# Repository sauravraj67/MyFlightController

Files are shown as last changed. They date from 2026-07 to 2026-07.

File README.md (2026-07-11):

# MyFlightController

Screenshot 2026-07-05 180633 (1)

So I made a custom flight controller which can be used for an RC Plane . it is based on STM32 and The Flight Controller  has 2 IMU's and a barometer for precise data collection. It has connectors for 2 Servos to control the wind / 2 ESCs and a reciever . It will work on a 12V battery. 

## Features
- Base on  STM32F401CBUx 
- Has dual IMU (MPU_6050)(ICM-20948)
- Has a Barometer (BMP280)
- Works on 12 V battery
- Has multiple voltage regulators for  (5v , 3.3v , 1.8v )

- ## 📦 Bill of Materials

| Item | Quantity | Unit Price (USD) | Total Price (USD) | Source |
|---|:---:|---:|---:|---|
| PCB + PCBA | 1 | $154.46 | $154.46 | https://jlcpcb.com |
| PCB Shipping | 1 | $17.32 | $17.32 | https://jlcpcb.com |

## 💰 Cost Summary

| Category | Amount (USD) |
|---|---:|
| Total Component Cost | **$171.78** |

### Schematic
Screenshot 2026-07-05 180633 (1)

 ### PCB Design 
 
 
  ### 3D View 

  Screenshot 2026-07-05 180633 (1)

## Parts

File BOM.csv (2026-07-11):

Item | Price | Source
PCB + PCBA | 154.46 | jlcpcb.com
PCB shipping | 17.32 | jlcpcb.com
Total | 171.78 | jlcpcb.com

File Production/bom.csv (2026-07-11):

Designator | Footprint | Quantity | Value | LCSC Part #
C1, C2, C3 | 0201 | 3 | 2u2
C10, C9 | 0201 | 2 | 0.1uf
C11, C18, C19 | 0201 | 3 | 10 uf
C12 | 0201 | 1 | 0.1 uf
C13, C14 | 0201 | 2 | 100 nf
C15, C16, C17 | 0201 | 3 | 100 n
C20, C21 | 0201 | 2 | 12pf
C22, C23, C24, C25, C26, C27 | 0201 | 6 | 100 pf
C4, C6 | 0201 | 2 | 100n
C5 | 0201 | 1 | 22u
C7, C8 | 0201 | 2 | 10uf
D1, D3 | 0201 | 2 | LED
D2 | 0201 | 1 | D
F1 | 0201 | 1 | Polyfuse
J1 | USB_C_Receptacle_G-Switch_GT-USB-7010ASV | 1 | USB_C_Receptacle_USB2.0_16P
J11, J12, J3, J5 | JST_EH_B3B-EH-A_1x03_P2.50mm_Vertical | 4 | Conn_01x03_Pin
J13 | JST_EH_B4B-EH-A_1x04_P2.50mm_Vertical | 1 | Conn_01x04_Pin
J2 | AMASS_XT60-M_1x02_P7.20mm_Vertical | 1 | Conn_01x02_Pin
J4, J6 | AMASS_XT60-F_1x02_P7.20mm_Vertical | 2 | Conn_01x02_Pin
Q1 | SOT-23 | 1 | AO3401A
R1, R2 | 0201 | 2 | 33 R
R3, R4 | 0201 | 2 | 50K
R5 | 0603 | 1 | 100R
R6, R7 | 0201 | 2 | 1K
SW1 | SW_PUSH_E-Switch_FS5700DP_DPDT | 1 | SW_DPDT_x2
SW2 | SW_Tactile_Straight_KSA0Axx1LFTR | 1 | SW_Push
U1 | TSOT-23-6 | 1 | AP63203WU
U2 | TO-252-2 | 1 | L7805
U3 | InvenSense_QFN-24_4x4mm_P0.5mm | 1 | MPU-6050
U4 | Bosch_LGA-8_2x2.5mm_P0.65mm_ClockwisePinNumbering | 1 | BMP280
U5 | InvenSense_QFN-24_3x3mm_P0.4mm | 1 | ICM-20948
U6 | SOT-23-5 | 1 | LD39015M18R
U7 | QFN-48-1EP_7x7mm_P0.5mm_EP5.6x5.6mm | 1 | STM32F401CBUx
Y1 | Crystal_SMD_0603-4Pin_6.0x3.5mm | 1 | Crystal_GND24_Small

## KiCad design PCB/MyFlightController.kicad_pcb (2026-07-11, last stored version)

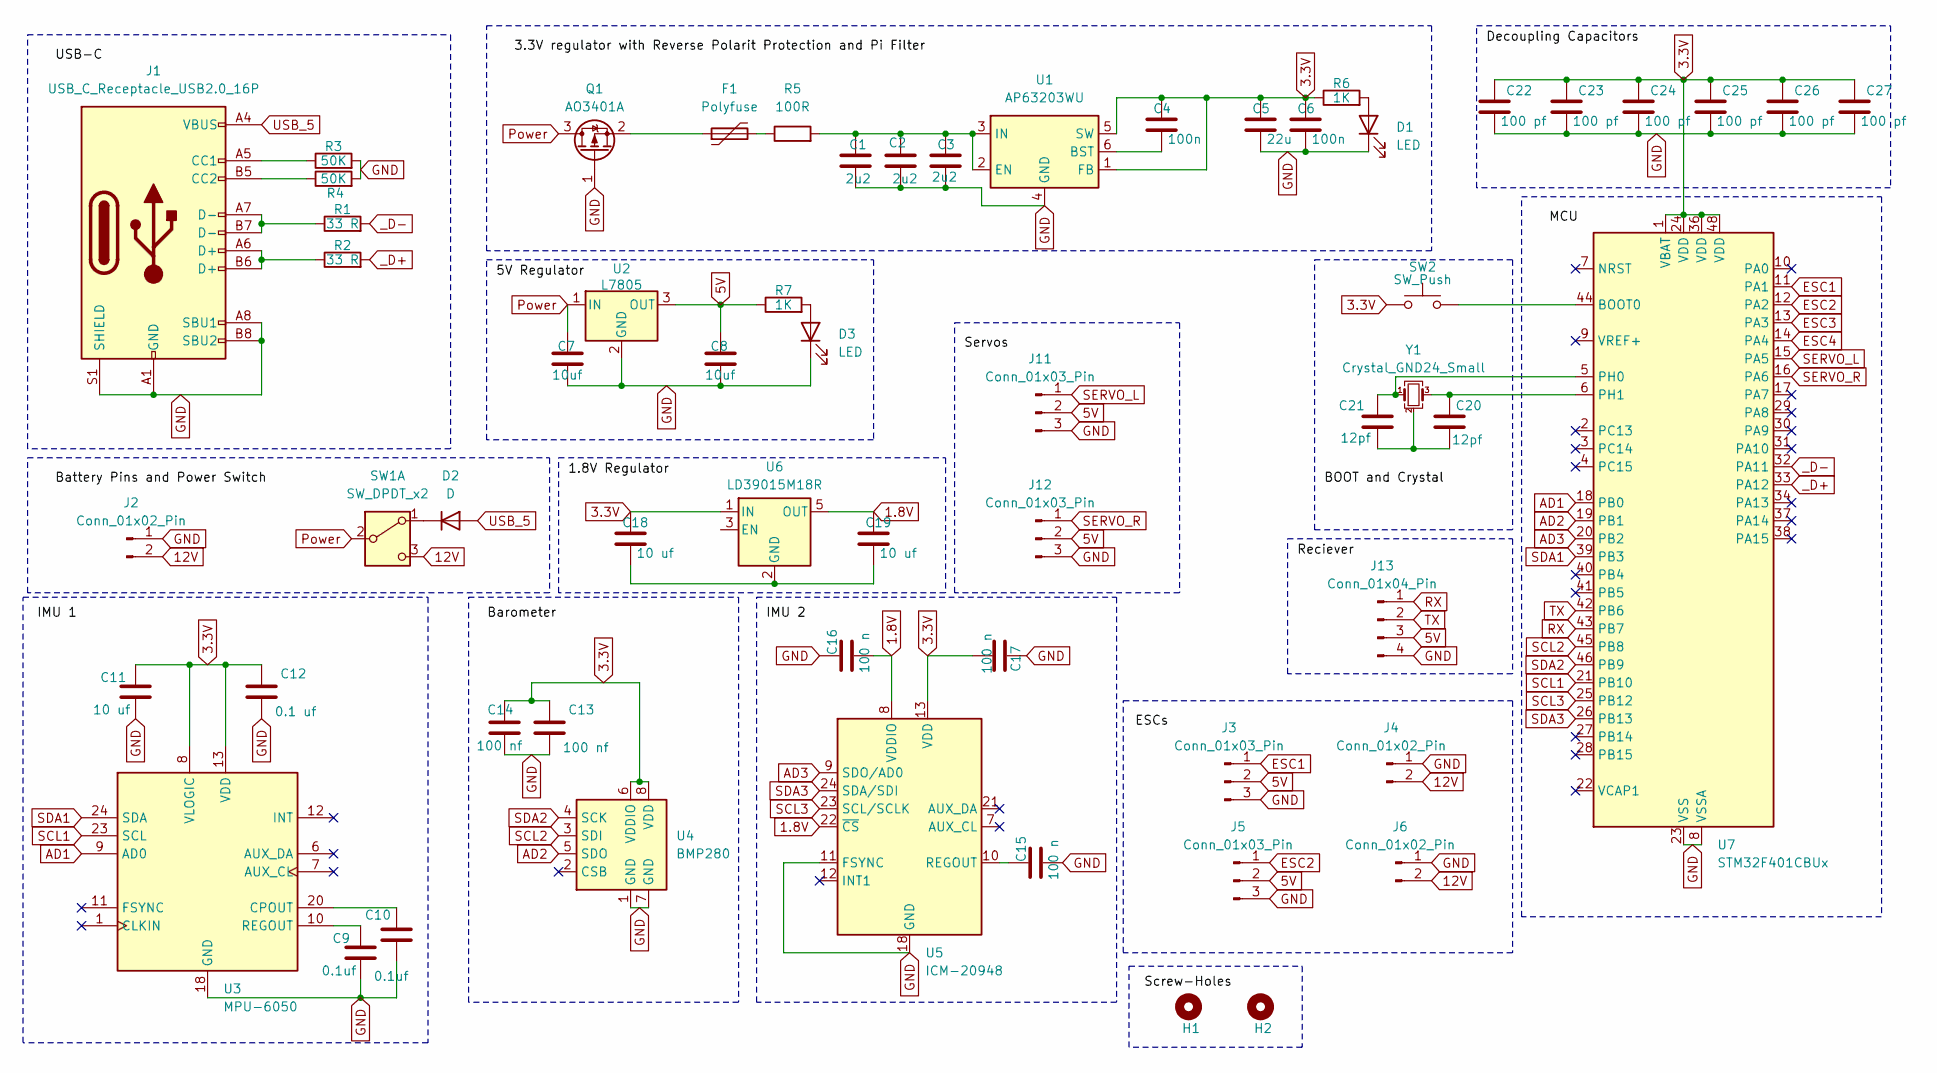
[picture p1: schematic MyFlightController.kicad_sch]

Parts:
C1, C2, C3: 2u2; C_0201_0603Metric
C4, C6: 100n; C_0201_0603Metric
C5: 22u; C_0201_0603Metric
C7, C8: 10uf; C_0201_0603Metric
C9, C10: 0.1uf; C_0201_0603Metric
C11, C18, C19: 10 uf; C_0201_0603Metric
C12: 0.1 uf; C_0201_0603Metric
C13, C14: 100 nf; C_0201_0603Metric
C15, C16, C17: 100 n; C_0201_0603Metric
C20, C21: 12pf; C_0201_0603Metric
C22, C23, C24, C25, C26, C27: 100 pf; C_0201_0603Metric
D1, D3: LED; LED_0201_0603Metric
D2: D; D_0201_0603Metric
F1: Polyfuse; C_0201_0603Metric
H1, H2: MountingHole; MountingHole_2.5mm_Pad
J1: USB_C_Receptacle_USB2.0_16P; USB_C_Receptacle_G-Switch_GT-USB-7010ASV
J2: Conn_01x02_Pin; AMASS_XT60-M_1x02_P7.20mm_Vertical
J3, J5, J11, J12: Conn_01x03_Pin; JST_EH_B3B-EH-A_1x03_P2.50mm_Vertical
J4, J6: Conn_01x02_Pin; AMASS_XT60-F_1x02_P7.20mm_Vertical
J13: Conn_01x04_Pin; JST_EH_B4B-EH-A_1x04_P2.50mm_Vertical
Q1: AO3401A; SOT-23
R1, R2: 33 R; R_0201_0603Metric_Pad0.64x0.40mm_HandSolder
R3, R4: 50K; R_0201_0603Metric_Pad0.64x0.40mm_HandSolder
R5: 100R; R_0603_1608Metric
R6, R7: 1K; R_0201_0603Metric_Pad0.64x0.40mm_HandSolder
SW1: SW_DPDT_x2; SW_PUSH_E-Switch_FS5700DP_DPDT
SW2: SW_Push; SW_Tactile_Straight_KSA0Axx1LFTR
U1: AP63203WU; TSOT-23-6
U2: L7805; TO-252-2
U3: MPU-6050; InvenSense_QFN-24_4x4mm_P0.5mm
U4: BMP280; Bosch_LGA-8_2x2.5mm_P0.65mm_ClockwisePinNumbering
U5: ICM-20948; InvenSense_QFN-24_3x3mm_P0.4mm
U6: LD39015M18R; SOT-23-5
U7: STM32F401CBUx; QFN-48-1EP_7x7mm_P0.5mm_EP5.6x5.6mm
Y1: Crystal_GND24_Small; Crystal_SMD_0603-4Pin_6.0x3.5mm

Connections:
1.8V: C16.2, C19.1, U5.8 (VDDIO), U5.22 (~CS), U6.5 (OUT)
3.3V: C4.1, C5.1, C6.1, C11.1, C12.1, C13.1, C14.1, C17.2, C18.1, C22.1, C23.1, C24.1, C25.1, C26.1, C27.1, R6.1, SW2.1, U1.1 (FB), U1.5 (SW), U3.8 (VLOGIC), U3.13 (VDD), U4.6 (VDDIO), U4.8 (VDD), U5.13 (VDD), U6.1 (IN), U7.1 (VBAT), U7.24 (VDD), U7.36 (VDD), U7.48 (VDD)
5V: C8.1, J3.2, J5.2, J11.2, J12.2, J13.3, R7.1, U2.3 (OUT)
12V: J2.2, J4.2, J6.2, SW1.3 (C)
AD1: U3.9 (AD0), U7.18 (PB0)
AD2: U4.5 (SDO), U7.19 (PB1)
AD3: U5.9 (SDO/AD0), U7.20 (PB2)
ESC1: J3.1, U7.11 (PA1)
ESC2: J5.1, U7.12 (PA2)
ESC3: U7.13 (PA3)
ESC4: U7.14 (PA4)
GND: C1.2, C2.2, C3.2, C5.2, C6.2, C7.2, C8.2, C9.2, C10.2, C11.2, C12.2, C13.2, C14.2, C15.2, C16.1, C17.1, C22.2, C23.2, C24.2, C25.2, C26.2, C27.2, D1.1 (K), D3.1 (K), J1.A1 (GND), J1.A8 (SBU1), J1.A12 (GND), J1.B1 (GND), J1.B8 (SBU2), J1.B12 (GND), J1.S1 (SHIELD), J2.1, J3.3, J4.1, J5.3, J6.1, J11.3, J12.3, J13.4, Q1.1 (G), R3.2, R4.2, U1.4 (GND), U2.2 (GND), U3.18 (GND), U4.1 (GND), U4.7 (GND), U5.11 (FSYNC), U5.18 (GND), U5.20 (GND), U7.8 (VSSA), U7.23 (VSS), U7.35 (VSS), U7.47 (VSS), U7.49 (VSS)
unnamed: C20.2, C21.2, Y1.2 (G), Y1.4 (G)
unnamed: D1.2 (A), R6.2
unnamed: D2.1 (K), SW1.1 (A)
unnamed: D3.2 (A), R7.2
unnamed: F1.2, R5.1
unnamed: J1.A5 (CC1), R3.1
unnamed: J1.B5 (CC2), R4.1
unnamed: J1.A6 (D+), J1.B6 (D+), R2.1
unnamed: J1.A7 (D-), J1.B7 (D-), R1.1
unnamed: F1.1, Q1.2 (S)
unnamed: C4.2, U1.6 (BST)
unnamed: C1.1, C2.1, C3.1, R5.2, U1.2 (EN), U1.3 (IN)
unnamed: C10.1, U3.20 (CPOUT)
unnamed: C9.1, U3.10 (REGOUT)
unnamed: C15.1, U5.10 (REGOUT)
unnamed: C18.2, C19.2, U6.2 (GND)
unnamed: SW2.2, U7.44 (BOOT0)
unnamed: C21.1, U7.5 (PH0), Y1.1
unnamed: C20.1, U7.6 (PH1), Y1.3
Power: C7.1, Q1.3 (D), SW1.2 (B), U2.1 (IN)
RX: J13.1, U7.43 (PB7)
SCL1: U3.23 (SCL), U7.21 (PB10)
SCL2: U4.3 (SDI), U7.45 (PB8)
SCL3: U5.23 (SCL/SCLK), U7.25 (PB12)
SDA1: U3.24 (SDA), U7.39 (PB3)
SDA2: U4.4 (SCK), U7.46 (PB9)
SDA3: U5.24 (SDA/SDI), U7.26 (PB13)
SERVO_L: J11.1, U7.15 (PA5)
SERVO_R: J12.1, U7.16 (PA6)
TX: J13.2, U7.42 (PB6)
USB_5: D2.2 (A), J1.A4 (VBUS), J1.A9 (VBUS), J1.B4 (VBUS), J1.B9 (VBUS)
_D+: R2.2, U7.33 (PA12)
_D-: R1.2, U7.32 (PA11)

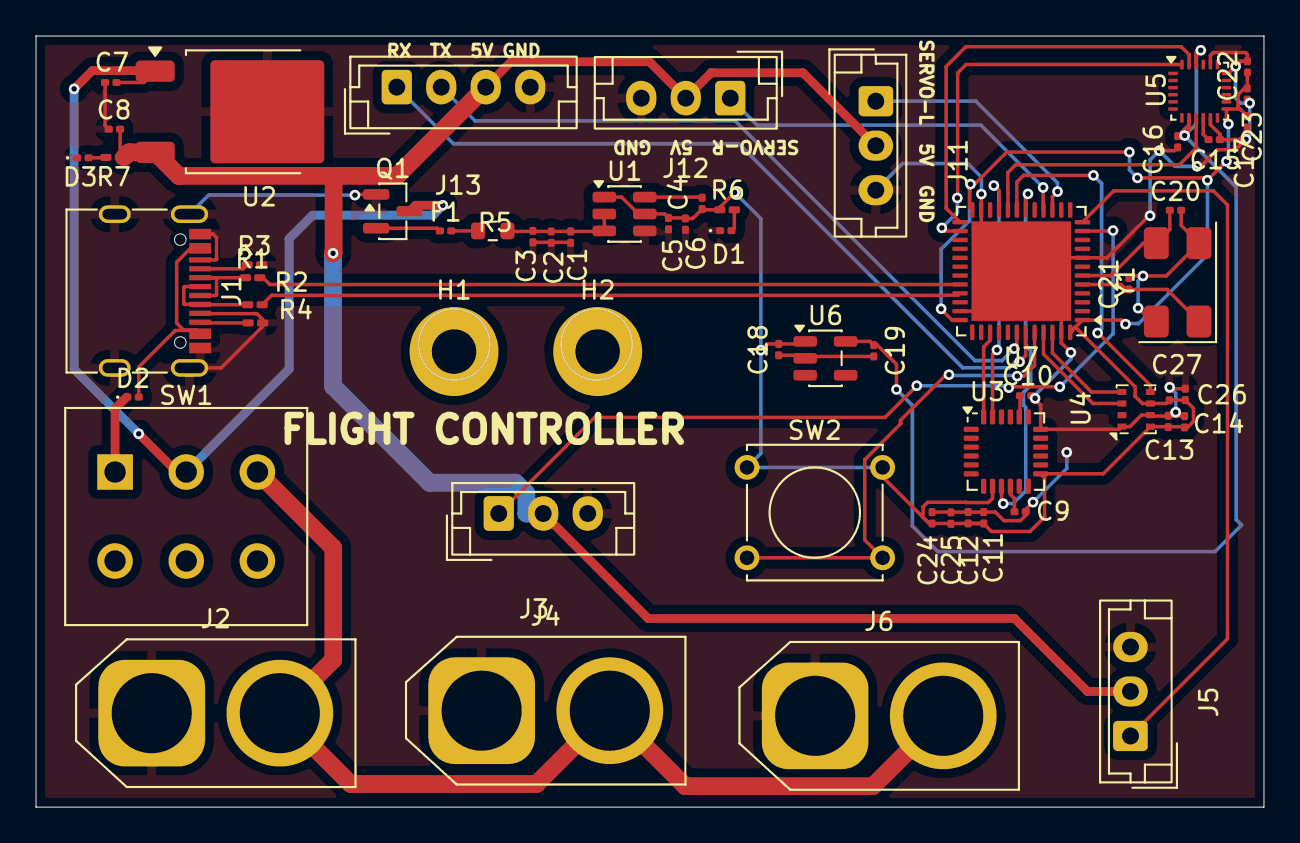
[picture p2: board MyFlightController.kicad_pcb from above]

Board: 2 copper layers, 69.0 x 43.3 mm, 60 parts (0 on the bottom side), 43 nets.

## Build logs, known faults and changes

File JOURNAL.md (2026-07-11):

### Schematic<br>

## Making the Schematics for Flight Controller (Part-1)
Hours- 4 hr <br>

I started with the Schematics part . I added USB-C Symbol and added the necessary resistors (33R for data lines and 50K for CC )and I added the label to it . I made sure that the Data label are named as _D+/_D- for not having an issuer While routing differential pair.



then I added a connector for Battery Connection (I will be using a 12V battery here) and a switch button to switch the Power connection between USB-C and the battery as per the need (USB-C for firmware update and Battery for flying).



. We Receive voltages at 5V from USB-C line and 12 V from battery but the MCU that we will be using (STM32) needs voltage at a constant 3.3V . So I need to add a 3.3V Voltage regulator so for that I choose AP63203WU as it fit's our needs the best then for extra Security / precaution (because power form it will go to the IMU and main sensors) , I added a reverse polarity filter using (AO3401A ) and added Pi-Filter then I added the respective capacitors as required by the circuit and added a fusion and an LED for detection and at the end added the respective labels. So this is how it looks



then I need to add a 5v Buck converter for powering the servos , receiver and the ESC's . So for that I choose (L7805). It has a very basic circuit SO I made it and added the respective capacitors of the needed values and added the label .


I didn't added any external filter over here because it wasn't much necessary.(As it is just for output devices like ESC's and servos) then It was the time to add an IMU . SO for the first IMU I went with (MPU-6050). as It is widely available and easy to integrate . It needed 3.3V logic so I didn't need to make any extra regulators for it and it will communicate through I2C to the IMU. So I made the respective circuit and added the label to the respective places and this is how it looks



## Making the Schematics for Flight Controller (Part-2)

Hours :- 6.25 hr 

Now I started with adding the Barometer (BMP280). It will help us to determine/hover at an altitude. It too works on 3.3V and will use I2C communication to IMU. SO I added it to the schematics and had a view to the datasheet and made it's circuit with the respected capacitors. then I added the labels and this is how it looks



. Then it was time to add the second IMU . after some consideration I choose (ICM-20948) for the Job. It too communicates via I2C but one difference was that it worked on 1.8 V . So firstly I had to make a 1.8 V voltage regulator . For that I went with (LD39015M18R) then I made it's circuit and added the labels



. I didn't used ant external filters like pi/reverse polarity because the connect source for it is 3.3V and it has all of these things from before. After that I moved to make the circuit schematics for the ICM-20948 . I added the labels and this is how it looks


Then I added two ESC's Connectors to control the brush less motor's. (One on each wing). Each ESC's has 2 set of connection . 3 pin connector (data,power,gnd) this goes onto connecting esc to IMU so that it could read at which speed should it make the motor rotate. and 2 pain (12V, GND) It is basically to power the Brushless Motor. So I added it with the labels and this is how it looks like


. After that I added 2 Servos connection (one for each wing). So that control the flap angle on each wing (To make the plane hover correctly). It has a single 3 pin connector (Data,Power,Gnd). SO i added them and placed the respective labels After this I went with added connector for the radio receiver. It has 4 Pin (RX,TX,Power,Gnd). RX and TX are for communication to IMU. So I added the connectors for it



 So Now Most of the things were done . Only STM32 connectors are left now So I began with it. First I needed to choose a STM32 Version . For that I went with STM32F401CBUx because it has enough Gpio and can handle the Flight computation . Also a good thing is that I don't need to add any extrenal flash to it becuase it comes with inbuild 128 KB of Flash memory and 64 KB of SRAM . At first I added the boot button and a 24 MHz Crysal oscillator with it's circuit to the MCU .
 

then I added 6 100pf Decoupling capacitors to the MCU . (2 near each sensors) and attached it to MCU

and then at the END I attached all the labels to the MCU (Data, 3 pair of I2C from sensors , 2 pair of ESC's and servos and the 2 connection form the receiver , and rest power Gnd oscillator things ). I made sure that I connected each connection at the right place as er the pin layout  and this is the final look of the schematics Screenshot 2026-07-05 131710 (1)

###  PCB Design<br><br>

## Started with PCB ( Component placement)
hours :- 5.2 hr
So I started with designing the PCB Layout . First I updated the PCB with the schematics and this is how it looked


then I started with arranging the main components in a rough manner (MCU , Sensor , USB ,Voltage regulators), then I started arranging the other small components (Like Resistors and capacitors) near to there connection I a proper manner So there would be easy while routing. after I completed that I Started placing all the small circuit clusters onto the board In a standard manner . I wanted the board to hold a rectangular dimension. So I made sure to maintain that shape while placing the components also made sure that there is enough space for routing and components are placed specifically that there rout are clean and short. at the end I placed all the connectors pins for the ESC , receiver and servos. I went for few alteration but ended up with this



.after that I added the Holes for connection and them made added the boundary and this is the final look of it then at the end added the text logo and connection guiled for each of the connection.





 ### Routing the PCB (Part-1)
Hours :- 4.1 hr 

So I started with routing the PCB firstly I routed the USB-C and the differential pair for data.



then I made connection for the power system


after that I started routing the Sensors circuit


after that I made more circuit connections

and then I started joining the SDA and SCL AD connections from Sensores to the MCU. Where wthere wasn't a way to rout I used vias to keep the circuit clean



after all this there were still many connection that I left like the boot pin and the servos So I routed it



. Many a Places 5V connection was missing to I used vias and routed it . I used Thick Routs for the 12V and 5V connections. again I saw the board and receivers data connections rout were missing anf this is how the PCB looks now 



SO I started routing it I had a bit of issues as the routs were very close and I wasn't able to make a rout
SO I made few changes in the rout , It took me a bit of time but I was able to rout it through .


Some places Power connection were missing SO I needed to rout it


I left the GND Connection and 3.3V Connection in major places because I will be using Fillzone of them on top and bottom Layer. So there were some more visual connections left SO I tried to join them all and this is how the PCB Looks now 


I added  the fill zones (Top layer is 3.3V and bottom layer is GND ) PCB Look after fillzone 




 ### Routing the PCB (Polishing The Rout / Fixing the errors and Disconnection )
Hours :- 3.75 hr 

So there were many not perfect routs on the board

Screenshot 2026-07-05 171402 (1)

and the board had many disconnections as well


. So I started solving them one by one . I will start with fixing the connections then I will move to Check things by rule checker and at the end I will polish all the routs . So I Saw multiple disconnection On the PCB and started Solving them one by one . I tried to keep the rout as simple as possible these are few of the 3.3V and GND connections that I solved






. Many places it was almost impossible to rout around but I did it somehow via changing the existing Rout and things. So this is how the PCB Looks after the update



 There were No mis-connecton left I checked it from the rule checker 

 . Now It is the last step after which the PCB work will be finished that Is Polishing the routs . So there are many not well routed rout (That I missed or changed it's path while I routed other rout may be due to overlapping of routs ). Like this Before
 

And After 

. I did this for many other places and these are the few after result





. This thing isn't compulsory but it increases the efficiency of the of the Board hence will help us in the project . So this is the final PCB look

In 3D
 Screenshot 2026-07-05 180633 (1)
